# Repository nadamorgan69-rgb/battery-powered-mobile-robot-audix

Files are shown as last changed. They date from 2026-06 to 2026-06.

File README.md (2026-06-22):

# Battery Powered Mobile Robot - Audix

Audix is a battery-powered mobile robot developed for warehouse-style auditing, navigation, sensing, and low-level motion control. This repository brings together the project software, simulation work, embedded control code, electrical design files, documentation, media, and test assets in one place.

## Project Overview

Audix combines several connected subsystems:

- ROS 2 robot software for mission control, sensing, dashboard access, and service orchestration
- Gazebo and RViz simulation assets for robot visualization and behavior testing
- ESP32 embedded control and bench firmware for mecanum motion, PID tuning, IMU feedback, and hardware validation
- electrical design resources including battery sizing, wiring, PCB files, and LTspice documentation
- project documentation, archive files, images, and simulation videos

## Key Components

- `source-repositories/ros2_ws/`
  ROS 2 runtime workspace for the robot stack, micro-ROS communication, GPIO control, vision, dashboard services, and mission flow.

- `source-repositories/Audix/`
  Simulation-focused robot package including URDF, Gazebo launch files, RViz configuration, controllers, and robot meshes.

- `source-repositories/esp32-mecanum-yaw-hold/`
  Standalone ESP32 bench firmware for mecanum yaw hold, heading correction, wheel RPM validation, and control tuning.

- `source-repositories/aduix-esp32-windows-test/`
  Windows-based ESP32 testing sandbox for isolated hardware bring-up, motor checks, IMU checks, encoder validation, and stepper testing.

## Repository Layout

- `documentation/`
  Final project report and written documentation.

- `electrical/battery-sizing/`
  Battery sizing calculations and related electrical planning files.

- `electrical/wiring-schematic/`
  Wiring schematic and Fritzing-based electrical layout files.

- `electrical/pcbs-full-files/`
  PCB project source files.

- `electrical/ltspice-simulation/`
  LTspice simulation documentation.

- `archives/`
  Project archive files and packaged design assets.

- `assets/images/`
  Robot photos, rendered visuals, and PCB screenshots.

- `assets/videos/`
  Simulation videos and recorded motion results.

## Project Images

### Physical Robot

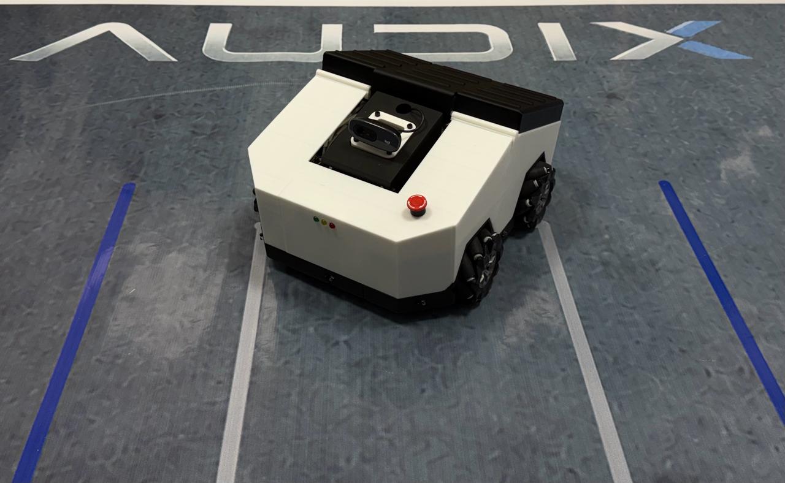
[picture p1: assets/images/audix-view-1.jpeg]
Audix view 1


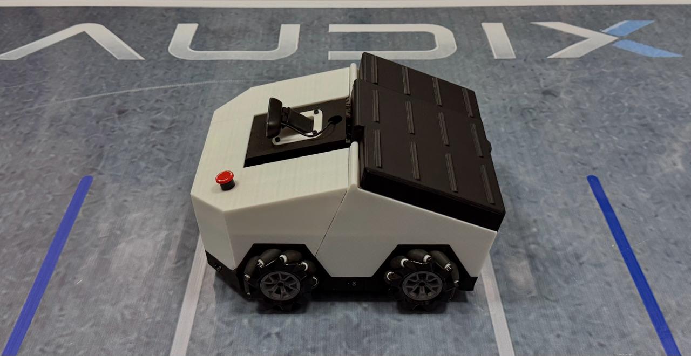
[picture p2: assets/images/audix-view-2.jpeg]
Audix view 2


### Design And PCB Visuals

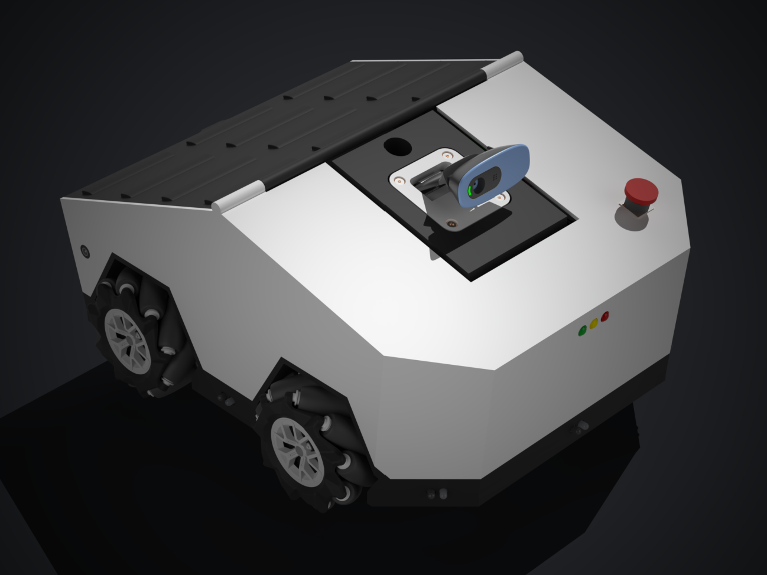
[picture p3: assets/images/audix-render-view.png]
Audix render view


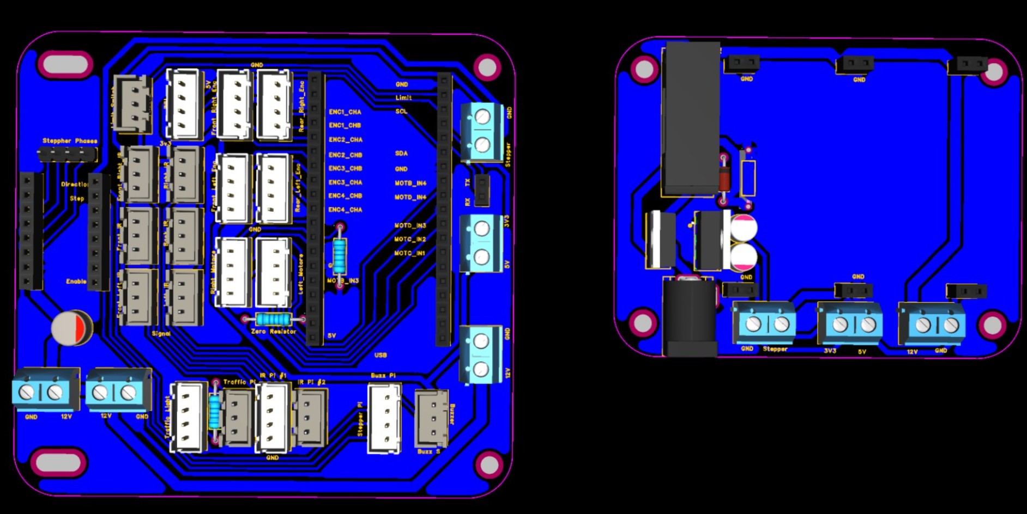
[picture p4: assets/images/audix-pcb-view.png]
Audix PCB view


## Main Project Files

- Final documentation: `documentation/audix-final-documentation.pdf`
- User manual: `documentation/AUDIX_User_Manual_landscape_no_margin/AUDIX_User_Manual_landscape_no_margin.pdf`
- Final poster: `documentation/Final Poster (1)/Final Poster (1).pdf`
- Team's card: `documentation/Audix ( Team's Card)/Audix ( Team's Card).pdf`
- Battery sizing: `electrical/battery-sizing/battery-sizing.pdf`
- Wiring schematic: `electrical/wiring-schematic/fritzing-version-1-stepper-ir.fz`
- PCB project: `electrical/pcbs-full-files/design-2.eprj`
- LTspice simulation: `electrical/ltspice-simulation/ltspice-simulation.pdf`
- Project archive: `archives/audix-mk1.rar`
- Full Mission video: `assets/videos/full-mission.mp4`

## Simulation Media

- `assets/videos/full-mission.mp4` - Full Mission
- `assets/videos/midterm-simulation-1.mp4`
- `assets/videos/midterm-simulation-2.mp4`
- `assets/videos/midterm-simulation-3.mp4`

## Notes

- Large media files such as `.rar` archives and `.mp4` videos are tracked with Git LFS.
- This repository is organized as a full project record, covering software, hardware, design, and documentation together.

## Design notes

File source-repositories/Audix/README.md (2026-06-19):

# Audix ROS2 Simulation Workspace

## Project Status (Where We Reached)
This workspace has been migrated to ROS 2 (Jazzy) with Gazebo (ros_gz) and is currently running a working simulation pipeline for the Audix robot.

Implemented so far:
- ROS 2 package setup with `ament_cmake` and install rules.
- Gazebo simulation launch with world loading and robot spawning.
- URDF integration with `robot_state_publisher`.
- `ros_gz_bridge` topic bridges for clock, odometry, joint states, IMU, lidar scan, and velocity command.
- `ros2_control` + `diff_drive_controller` integration.
- EKF localization node (`robot_localization`) enabled for fused state estimation.
- RViz launch and default visualization config.
- Initial behavior scripts for obstacle avoidance and waypoint motion.

Current known scope:
- Main drivetrain currently behaves as differential drive in simulation.
- Team roadmap below includes planned migration/tuning toward mecanum-specific behavior and a fuller warehouse-like environment.

## Quick Start
Use these commands from the repository root:

```bash
source /opt/ros/jazzy/setup.bash
colcon build --packages-select audix
source install/setup.bash
```

Launch Gazebo simulation:

```bash
ros2 launch audix robot_gazebo.launch.py
```

Launch RViz visualization-only flow:

```bash
ros2 launch audix display_rviz.launch.py
```

## What Each Launch File Does
- `src/audix_pkg/launch/robot_gazebo.launch.py`
  - Main simulation entrypoint.
  - Starts Gazebo, robot state publisher, bridges, robot spawn, and EKF.
- `src/audix_pkg/launch/gazebo.launch.py`
  - Wrapper that includes `robot_gazebo.launch.py`.
- `src/audix_pkg/launch/display_rviz.launch.py`
  - RViz-focused launch (URDF, joint state publisher/gui, robot state publisher, RViz2).
- `src/audix_pkg/launch/display.launch.py`
  - Wrapper that includes `display_rviz.launch.py`.

## Config and World Files (High-Level)
- `src/audix_pkg/config/controllers.yaml`
  - Controller manager and drive controller parameters (wheel names, geometry, limits, cmd format).
- `src/audix_pkg/config/ekf.yaml`
  - EKF fusion settings (odom + IMU) and TF publishing behavior.
- `src/audix_pkg/rviz/config.rviz`
  - Default RViz display layout and fixed frame.
- `src/audix_pkg/world/my_world.sdf`
  - Main simulation world (ground plane, lighting, example obstacle, physics/sensor systems).
- `src/audix_pkg/world/empty_world.sdf`
  - Minimal baseline world variant.

## Simulation Pipeline Overview
1. Build and source the workspace.
2. Launch Gazebo world.
3. Publish robot URDF to `robot_description`.
4. Spawn robot entity in Gazebo from `robot_description`.
5. Bridge Gazebo/ROS topics (`/clock`, `/odom`, `/imu`, `/scan`, `/joint_states`, `/cmd_vel`).
6. Run control and localization (`ros2_control`, diff drive, EKF).
7. Optionally visualize in RViz.

## Team Roadmap (Organized TODO)

### A. Robot Frames, Geometry, and Spawn Accuracy
1. Make `RobotBody` coincide with the robot CG (not a corner/reference artifact).
2. Update spawn height so robot starts above the floor by the CG-to-lowest-wheel-point offset.
3. Add dedicated IR sensor frames in SolidWorks and keep URDF frame mapping consistent.
4. Add a frame at the exact IMU location for accurate simulation alignment (IMU frame can differ from CG).
5. Simplify RViz defaults by hiding extra mechanism links that reduce readability.

### B. Mecanum Drivetrain Study and Motion Mapping
1. Study mecanum wheel kinematics and control requirements.
2. Define and validate motion mapping for: forward, backward, left, right, rotate, and combined steering.
3. Ensure controller architecture supports mecanum behavior instead of diff-drive assumptions where needed.

### C. Environment and Obstacles
1. Define dynamic obstacle strategy:
   - How many obstacles.
   - Spawning method.
   - Motion behavior and test scenarios.
2. Design shelves and inventory layout to match the expected real environment.
3. Build the full Gazebo environment to reflect expected operational conditions.

### D. Controls, Scripts, and Mechanism Automation
1. Decide what extra scripts are required and how customizable the GUI/control interface should be.
2. Integrate scissor-lift motion mapping (from MATLAB) into an automation script:
   - Camera height command in.
   - Coordinated link motion out.

### E. Midterm Planning and Validation Scope
1. Prepare a clear checklist of all midterm deliverables and acceptance criteria.
2. Decide perception scope:
   - Whether camera sensing/object detection is required in simulation.
   - Required reactions/behaviors if detection is enabled.

### F. Data, Calibration, and Visual Fidelity
1. Collect and track all key dimensions, speeds, and relevant physical parameters to improve simulation accuracy.
2. Apply robot coloring/material styling for clearer visualization and team demos.

## Editing Guidance (For Future Team Members)
- Adjust drivetrain and controller behavior in `config/controllers.yaml` and matching wheel/joint definitions in URDF.
- Update localization behavior in `config/ekf.yaml`.
- Modify world geometry and obstacles in `world/my_world.sdf`.
- Keep frame naming consistent across SolidWorks export, URDF, controllers, and RViz.
- After any change:
  1. Rebuild package.
  2. Re-source `install/setup.bash`.
  3. Relaunch and validate topics/TF.

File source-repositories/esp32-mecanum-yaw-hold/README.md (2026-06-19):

# ESP32 Mecanum Yaw Hold Bench

Standalone Audix-aligned ESP32 test firmware for mecanum yaw hold, straight-line
heading correction, wheel RPM validation, and a small HTTP dashboard.

This repo is intentionally separate from the real firmware folders:

- read-only reference sandbox: `C:\Users\TiBa\Documents\PlatformIO\Projects\audix_esp32_windows_test`
- read-only final Pi firmware: `C:\Users\TiBa\OneDrive\Spring 26\Design 2\audix_wps\microROS\firmware\esp32_low_level`
- editable yaw-hold test target: `C:\Users\TiBa\Documents\PlatformIO\Projects\esp32_mecanum_yaw_hold`

The old single-file `.ino` test sketch is not the active firmware path here.
This project mirrors the Audix Windows sandbox structure: `src/`, `include/`,
FreeRTOS tasks, shared state, IMU driver, encoder odometry, mecanum kinematics,
wheel PID, HTTP API, and a SPIFFS dashboard.

## What Changed

- Added explicit `imu cal`, `imu zero`, and `imu reset` commands.
- Added `yawhold zero`, `yawhold on`, and `yawhold off`.
- Straight `forward <cm>` and `backward <cm>` now keep heading hold active at
  the captured starting yaw after the distance target finishes.
- Still yaw hold commands chassis `wz` through the normal mecanum inverse
  kinematics path instead of directly poking wheel RPMs.
- Added a zero-output gate in the wheel PID task so tiny target and encoder
  noise near zero does not get boosted into audible motor-deadband ticks.
- Extended `/api/state` with heading and command-path diagnostics.
- Simplified the dashboard to the yaw-hold bench flow: setup, hold/release,
  forward/backward/rotate, RPM validation, wheel/yaw PID tuning, and raw log.

## Build

```powershell
cd "C:\Users\TiBa\Documents\PlatformIO\Projects\esp32_mecanum_yaw_hold"
pio run -e esp32_wifi_base_dashboard
pio run -e esp32_wifi_base_dashboard -t buildfs
```

## Flash Over USB

Replace `COM10` if your ESP32 is on another port.

```powershell
cd "C:\Users\TiBa\Documents\PlatformIO\Projects\esp32_mecanum_yaw_hold"
pio run -e esp32_wifi_base_dashboard -t upload --upload-port COM10
pio run -e esp32_wifi_base_dashboard -t uploadfs --upload-port COM10
```

If you need to find the port:

```powershell
pio device list
```

Serial monitor:

```powershell
pio device monitor -p COM10 -b 115200
```

## Open The GUI

Connect the laptop to:

```text
SSID: AudixBench-ESP32
Password: audixbench123
```

Open:

```text
http://192.168.4.1/
```

Direct API checks:

```text
http://192.168.4.1/api/ping
http://192.168.4.1/api/state
http://192.168.4.1/api/history
http://192.168.4.1/api/command?line=status
```

## Hardware Mapping

Firmware wheel order is `FL, FR, RL, RR`.

| Wheel | Motor label | Motor GPIOs | Encoder label | Encoder GPIOs |
| --- | --- | --- | --- | --- |
| Front Left | MOTD | `17, 18` | ENC2 | `34, 35` |
| Front Right | MOTB | `13, 19` | ENC3 | `33, 32` |
| Rear Left | MOTC | `4, 16` | ENC1 | `39, 36` |
| Rear Right | MOTA | `27, 14` | ENC4 | `25, 26` |

The motor driver is two-input H-bridge style:

- positive command: `IN1 = PWM`, `IN2 = LOW`
- negative command: `IN1 = LOW`, `IN2 = PWM`
- stop: both inputs `LOW`

## Fast Bench Flow

Keep the robot on blocks until wheel direction, encoder mapping, RPM feedback,
and stop behavior are correct.

```text
stop
i2cscan
imu cal
encoders zero
rpm fl 60 2.0
rpm fr 60 2.0
rpm rl 60 2.0
rpm rr 60 2.0
rpms all 60 2.0
yawhold zero
```

Twist the robot by hand and release it. Expected result:

- it returns to the captured yaw
- heading error returns inside `+/-3 deg` without repeated sign-flip hunting
- `heading.commandWz` returns to `0`
- wheel PWM returns to `0` when settled

Then test commanded motion:

```text
forward 20
backward 20
rotate 90
rotate -90
stop
```

`rotate 90` means counter-clockwise. `rotate -90` means clockwise.

## Important Commands

```text
stop
status
quiet
i2cscan
imu cal
imu zero
imu reset
encoders zero
encoders once
encoders on
yawhold on
yawhold off
yawhold zero
forward 20
backward 20
rotate 90
rotate -90
rpm fl 60 2.0
rpms all 60 2.0
pid show
pid wheel 1.20 0.80 0.05
pid yaw 2.00 0.00 0.06
```

## Documentation

- `docs/yaw_hold_test_procedure.md`: hardware validation order and pass/fail criteria.
- `docs/tuning_guide.md`: 10 to 15 minute tuning procedure and symptom map.
- `docs/rtos_porting_notes.md`: how to move only the controller logic into the local RTOS firmware.
- `docs/architecture.md`: module map for this standalone test firmware.

## RTOS Applicability

If this test works, the yaw-hold controller is applicable to the local ESP32 RTOS
firmware. Port only the controller logic: angle wrapping, hold state, deadband,
P plus gyro damping, command clamp, zero-output gate, settle criteria, and
telemetry. Do not copy WebServer, SPIFFS dashboard, Arduino `String` JSON, or
sketch-specific command handlers into the RTOS firmware.

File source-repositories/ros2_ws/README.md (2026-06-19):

# Audix ROS 2 Workspace

This workspace runs the Audix Raspberry Pi robot stack. It connects the Pi, ESP32
micro-ROS firmware, GPIO hardware, IR sensors, scissor lift, webcam, YOLO shelf
scanner, robot mission manager, and a simple browser dashboard.

The main launcher is `robot_start.sh`. It starts the full robot stack and prints
the dashboard URL, normally `http://<pi-ip>:8080`.

## What This Workspace Does

Audix is a small warehouse audit robot. The ROS workspace:

- Receives telemetry from the ESP32 drive controller through micro-ROS.
- Sends drive commands to the ESP32 as text commands on a ROS topic.
- Reads six IR proximity sensors from Raspberry Pi GPIO.
- Controls a buzzer and stepper-driven scissor lift through Raspberry Pi GPIO.
- Runs a webcam node and a YOLO shelf scanning service.
- Provides high-level robot services for manual movement, rotation, homing, stop,
  and shelf audit missions.
- Serves a simple web dashboard that calls ROS services and displays telemetry,
  IR state, camera frames, mission events, and vision scan results.

## Packages

| Package | Purpose |
| --- | --- |
| `audix_interfaces` | Custom ROS messages and services used by the robot stack. |
| `audix_robot` | Pi-side control nodes, robot manager, GPIO hardware, micro-ROS bridge, and web dashboard. |
| `warehouse_vision` | Webcam publisher and YOLO shelf audit service. |
| `firmware/audix_esp32_microros` | ESP32 micro-ROS firmware. It subscribes to drive commands and publishes telemetry JSON. |

## Main Launch Files

| File | Purpose |
| --- | --- |
| `launch/audix_main.launch.py` | Full runtime stack used by `robot_start.sh`: micro-ROS agent, base node, GPIO node, manager, webcam, vision, dashboard. |
| `launch/audix_bridge.launch.py` | Smaller bridge-only launch: micro-ROS agent, base node, GPIO node. No manager, vision, or dashboard. |

Default namespace is `/audix`, so relative names like `esp/telemetry` appear as
`/audix/esp/telemetry`.

## Nodes Started By `robot_start.sh`

| Node | Package / executable | Main job |
| --- | --- | --- |
| `/micro_ros_agent` | `micro_ros_agent micro_ros_agent` | Serial micro-ROS transport to ESP32 on `/dev/ttyAMA0` by default. |
| `/audix/micro_ros_base` | `audix_robot micro_ros_base_node` | Converts ESP32 micro-ROS telemetry JSON into ROS messages and exposes low-level drive services. |
| `/audix/gpio_hardware` | `audix_robot gpio_hardware_node` | Reads IR sensors and controls buzzer/lift GPIO. |
| `/audix/robot_manager` | `audix_robot robot_manager_node` | High-level command gate, manual safety, homing, map audit mission, lift/vision orchestration. |
| `/audix/webcam` | `warehouse_vision webcam_node` | Publishes camera frames. |
| `/audix/vision_audit` | `warehouse_vision vision_audit_node` | Runs YOLO scan service for shelf/product checking. |
| `/audix/web_dashboard` | `audix_robot web_dashboard_node` | Serves the simple browser dashboard and HTTP API. |

When the ESP32 firmware is connected through the micro-ROS agent, it creates the
micro-ROS node `/audix/esp32_controller`. That firmware node subscribes to
`/audix/esp/move_goal` and publishes `/audix/esp/telemetry_json`.

## Other Executable Nodes

These console scripts are available from `setup.py` but are not launched by
`robot_start.sh`.

| Executable | Purpose |
| --- | --- |
| `terminal_move_node` | Keyboard/terminal client for direction moves, rotate, stop, reset odom, init IMU. |
| `terminal_teleop_node` | Keyboard/terminal RPM teleop using the `/audix/twist` service. |
| `hello_node` | Small test/demo node in `warehouse_vision`. |

There is also an older source file, `audix_robot/esp_uart_bridge_node.py`, for a
direct UART JSON bridge. It is not used by `robot_start.sh`; the current stack
uses micro-ROS.

## Topics

| Topic | Type | Publisher | Subscriber | Purpose |
| --- | --- | --- | --- | --- |
| `/audix/esp/move_goal` | `std_msgs/String` | `micro_ros_base_node` | ESP32 firmware | Text commands to the ESP32: `MOVE`, `TWIST`, `STOP`, `INIT_IMU`, `RESET_ODOM`, etc. |
| `/audix/esp/telemetry_json` | `std_msgs/String` | ESP32 firmware | `micro_ros_base_node` | Raw JSON telemetry from the ESP32. |
| `/audix/esp/telemetry` | `audix_interfaces/EspTelemetry` | `micro_ros_base_node` | `robot_manager_node`, `web_dashboard_node` | Parsed robot pose, IMU, move, RPM, PWM, encoder telemetry. |
| `/audix/esp/telemetry_raw` | `std_msgs/String` | `micro_ros_base_node` | Optional debug tools | Raw JSON telemetry republished for debugging. |
| `/audix/ir/state` | `audix_interfaces/IrState` | `gpio_hardware_node` | `robot_manager_node`, `web_dashboard_node` | Six binary IR sensor states and active sensor list. |
| `/audix/mission/event` | `std_msgs/String` | `robot_manager_node` | `web_dashboard_node` | Human-readable mission and safety events. |
| `/audix/vision/scan_result` | `std_msgs/String` JSON | `robot_manager_node` | `web_dashboard_node` | Latest audit scan result as JSON. |
| `/audix/image_raw` | `sensor_msgs/Image` | `webcam_node` | `vision_audit_node`, `web_dashboard_node` | Live camera frames. |

Note: the Next.js GUI joystick currently publishes `/cmd_vel` through rosbridge
when `NEXT_PUBLIC_ROSBRIDGE_URL` is set, but this ROS workspace does not launch a
node that subscribes to `/cmd_vel`. The working control path today is through the
manager services or the dashboard HTTP API.

## Messages

### `audix_interfaces/msg/EspTelemetry`

Parsed ESP32 telemetry:

- Header and `mode`, `seq`.
- IMU fields: `imu_ok`, `yaw_deg`, `raw_yaw_deg`, `gyro_dps`,
  `gyro_filt_dps`.
- Odom/move fields: `forward_cm`, `strafe_cm`, `progress_cm`,
  `remaining_cm`, `local_forward_cm`, `local_strafe_cm`, `move_phase`,
  `move_angle_deg`, `move_distance_cm`, `heading_target_deg`,
  `heading_error_deg`, `move_done`.
- Wheel fields: `rpm[4]`, `target_rpm[4]`, `pwm[4]`,
  `raw_encoder_counts[4]`, `signed_encoder_counts[4]`.
- `raw_json` copy of the source telemetry.

### `audix_interfaces/msg/IrState`

Six binary IR sensors:

- `front_left`, `front`, `front_right`, `right`, `back`, `left`
- `active`: names of sensors currently detecting an obstacle

## Services

All services below are normally under `/audix`.

| Service | Type | Server | Purpose |
| --- | --- | --- | --- |
| `/audix/esp/ping` | `std_srvs/Trigger` | `micro_ros_base_node` | Check for fresh ESP telemetry. |
| `/audix/esp/init_imu` | `std_srvs/Trigger` | `micro_ros_base_node` | Publish `INIT_IMU` to ESP32. |
| `/audix/esp/reset_odom` | `std_srvs/Trigger` | `micro_ros_base_node` | Reset Pi world odom accumulator and publish `RESET_ODOM`. |
| `/audix/esp/reset_encoders` | `std_srvs/Trigger` | `micro_ros_base_node` | Reset Pi odom accumulator and publish `RESET_ENC`. |
| `/audix/esp/stop` | `std_srvs/Trigger` | `micro_ros_base_node` | Publish `STOP` to ESP32. |
| `/audix/move` | `audix_interfaces/Move` | `micro_ros_base_node` | Low-level move by angle, distance, and heading. |
| `/audix/twist` | `audix_interfaces/TwistCommand` | `micro_ros_base_node` | Low-level RPM command: forward, strafe, turn. |
| `/audix/esp/raw_command` | `audix_interfaces/RawCommand` | `micro_ros_base_node` | Send custom ESP32 text command. |
| `/audix/gpio/set_buzzer` | `std_srvs/SetBool` | `gpio_hardware_node` | Turn buzzer on/off. |
| `/audix/lift/move_steps` | `audix_interfaces/LiftMoveSteps` | `gpio_hardware_node` | Move lift stepper by signed direction and step count. |
| `/audix/manager/set_mode` | `audix_interfaces/SetRobotMode` | `robot_manager_node` | Set `manual`, `mission`, or `idle`. |
| `/audix/manager/direction_move` | `audix_interfaces/DirectionCommand` | `robot_manager_node` | High-level safe movement using directions `F`, `B`, `L`, `R`, `FL`, `FR`, `BL`, `BR`. |
| `/audix/manager/rotate` | `audix_interfaces/RotateCommand` | `robot_manager_node` | Rotate left/right by degrees. |
| `/audix/manager/start_audit` | `audix_interfaces/AuditMission` | `robot_manager_node` | Start map audit mission for selected shelf sides and levels. |
| `/audix/manager/go_home` | `std_srvs/Trigger` | `robot_manager_node` | Return to odom zero/home. |
| `/audix/manager/stop` | `std_srvs/Trigger` | `robot_manager_node` | Cancel mission, stop robot, turn buzzer off, return to manual mode. |
| `/audix/scan_shelf` | `audix_interfaces/ShelfScan` | `vision_audit_node` | Run YOLO shelf scan on a fresh camera frame. |

## Custom Service Fields

| Type | Request | Response |
| --- | --- | --- |
| `Move` | `angle_deg`, `distance_m`, `heading_deg`, `timeout_s`, `wait_for_done` | `ok`, `result`, `message`, `forward_cm`, `strafe_cm`, `heading_deg`, `raw_json` |
| `TwistCommand` | `forward_rpm`, `strafe_rpm`, `turn_rpm`, `timeout_s` | `ok`, `message`, `raw_json` |
| `DirectionCommand` | `direction`, `distance_cm`, `timeout_s` | `ok`, `result`, `message`, `forward_cm`, `strafe_cm`, `heading_deg` |
| `RotateCommand` | `direction`, `degrees`, `timeout_s` | `ok`, `result`, `message`, `heading_deg` |
| `SetRobotMode` | `mode` | `ok`, `message`, `active_mode` |
| `LiftMoveSteps` | `steps`, `direction`, `speed_sps` | `ok`, `message` |
| `AuditMission` | `shelves`, `level_1`, `level_2` | `accepted`, `message` |
| `ShelfScan` | `shelf_id` | `success`, `shelf_id`, `expected_product`, `expected_count`, `detected_count`, `detected_products`, `wrong_products`, `confidence`, `status`, `message`, `image_path` |
| `RawCommand` | `command`, `timeout_s`, `wait_for_done` | `ok`, `type`, `result`, `message`, `raw_json` |

## Simple Web Dashboard

The simple GUI is served by `web_dashboard_node`, not by the Next.js app. Open:

```bash
http://<pi-ip>:8080
```

The dashboard shows:

- Current mode, last event, telemetry age, odom forward/strafe, yaw, IMU state,
  move state, and sequence number.
- Manual jog controls for 8 directions.
- Rotate left/right controls.
- STOP, home, init IMU, reset odom, buzzer, and lift controls.
- IR sensor indicators.
- Mission audit side/level selection.
- Live camera JPEG refreshed from the ROS image topic.
- Manual shelf scan and latest audit scan result/image.
- Log of HTTP API responses and mission events.

### Dashboard HTTP API

The browser calls these routes on the same Pi/dashboard host:

| Route | Method | Uses ROS service/topic |
| --- | --- | --- |
| `/` or `/index.html` | GET | Serves the dashboard HTML. |
| `/api/status` | GET | Returns cached `/audix/esp/telemetry`, `/audix/ir/state`, `/audix/mission/event`, latest scan. |
| `/api/camera.jpg` | GET | Returns latest JPEG encoded from `/audix/image_raw`. |
| `/api/audit_image?path=...` | GET | Returns annotated scan image from `~/audix/audit_images`. |
| `/api/move` | POST | Calls `/audix/manager/direction_move`. Body: `direction`, `distance_cm`, optional `timeout_s`. |
| `/api/rotate` | POST | Calls `/audix/manager/rotate`. Body: `direction`, `degrees`, optional `timeout_s`. |
| `/api/mode` | POST | Calls `/audix/manager/set_mode`. Body: `mode`. |
| `/api/audit` | POST | Calls `/audix/manager/start_audit`. Body: `shelves`, `level_1`, `level_2`. |
| `/api/stop` | POST | Calls `/audix/manager/stop`. |
| `/api/home` | POST | Calls `/audix/manager/go_home`. |
| `/api/init_imu` | POST | Calls `/audix/esp/init_imu`. |
| `/api/reset_odom` | POST | Calls `/audix/esp/reset_odom`. |
| `/api/buzzer` | POST | Calls `/audix/gpio/set_buzzer`. Body: `on`. |
| `/api/lift` | POST | Calls `/audix/lift/move_steps`. Body: `steps`, optional `direction`, optional `speed_sps`. |
| `/api/scan` | POST | Calls `/audix/scan_shelf`. Body: `shelf_id`. |

This HTTP API is the easiest bridge for an advanced GUI: keep the ROS stack
running on the Pi and have the new GUI call these endpoints.

## Next.js GUI In This Repo

There is also a separate advanced-looking Next.js GUI in:

```bash
../Audix_GUI/Audix_GUI
```

It currently uses `lib/mock-data.ts` for most robot, inventory, IR, health, and
log data. The joystick component can publish to rosbridge if
`NEXT_PUBLIC_ROSBRIDGE_URL` is set, but it publishes `geometry_msgs/Twist` to
`/cmd_vel`, and the current ROS stack does not subscribe to that topic.

To migrate this GUI to live robot data, use one of these paths:

1. Easiest path: call the existing dashboard HTTP API on port `8080`.
   - Read status from `GET http://<pi-ip>:8080/api/status`.
   - Show camera from `http://<pi-ip>:8080/api/camera.jpg`.
   - Move with `POST /api/move`.
   - Rotate with `POST /api/rotate`.
   - Stop with `POST /api/stop`.
   - Start audit with `POST /api/audit`.
   - Scan shelves with `POST /api/scan`.

2. More ROS-native path: run `rosbridge_server` and connect with `roslibjs`.
   - Subscribe to `/audix/esp/telemetry`, `/audix/ir/state`,
     `/audix/mission/event`, `/audix/vision/scan_result`, and `/audix/image_raw`
     or a compressed camera topic.
   - Call `/audix/manager/direction_move`, `/audix/manager/rotate`,
     `/audix/manager/stop`, `/audix/manager/start_audit`, `/audix/scan_shelf`,
     and the other services directly.
   - If you want joystick `/cmd_vel`, add a ROS node that subscribes to
     `/cmd_vel` and converts it into `/audix/twist` service calls, or change the
     GUI to call `/audix/twist` through rosbridge services.

3. Backend path: build a small Node/Python server beside the GUI.
   - The backend talks to ROS using `rclpy`, `rclnodejs`, or rosbridge.
   - The frontend talks to that backend over REST/WebSocket.
   - This is useful if the advanced GUI needs authentication, logging, or custom
     data shaping.

## How Data Moves Through The Robot

Command path:

```text
Browser dashboard or advanced GUI
  -> dashboard HTTP API or ROS service
  -> /audix/manager/* service
  -> /audix/move or /audix/twist service
  -> /audix/esp/move_goal topic
  -> ESP32 micro-ROS firmware
  -> motors / IMU / encoders
```

Telemetry path:

```text
ESP32 firmware
  -> /audix/esp/telemetry_json
  -> micro_ros_base_node
  -> /audix/esp/telemetry
  -> robot_manager_node and web_dashboard_node
  -> /api/status or advanced GUI ROS subscription
```

GPIO/safety path:

```text
Pi GPIO IR sensors
  -> gpio_hardware_node
  -> /audix/ir/state
  -> robot_manager_node safety logic
  -> /audix/esp/stop and buzzer when needed
```

Vision path:

```text
webcam_node
  -> /audix/image_raw
  -> vision_audit_node
  -> /audix/scan_shelf service
  -> robot_manager_node publishes /audix/vision/scan_result
  -> web_dashboard_node and GUI
```

## Running The Robot Stack

On the Raspberry Pi:

```bash
cd ~/path/to/ros2_ws
source /opt/ros/jazzy/setup.bash
colcon build --symlink-install
./robot_start.sh
```

Then open the URL printed by the script:

```bash
http://<pi-ip>:8080
```

The script automatically sources:

```bash
/opt/ros/jazzy/setup.bash
install/setup.bash
```

It also checks that `audix_robot`, `audix_interfaces`, and `micro_ros_agent` are
available before launching.

## Useful `robot_start.sh` Environment Variables

Set these before running `./robot_start.sh` when needed:

| Variable | Default | Purpose |
| --- | --- | --- |
| `AUDIX_PORT` | `/dev/ttyAMA0` | ESP32 micro-ROS serial port. |
| `AUDIX_BAUD` | `115200` | ESP32 serial baud rate. |
| `AUDIX_DASHBOARD_PORT` | `8080` | Web dashboard HTTP port. |
| `AUDIX_MOCK_IR` | `false` | Use mock IR sensor state. |
| `AUDIX_MOCK_GPIO` | `false` | Use mock GPIO outputs/lift/buzzer. |
| `AUDIX_CAMERA_ENABLED` | `true` | Start or skip webcam node. |
| `AUDIX_CAMERA_INDEX` | `0` | OpenCV camera index. |
| `AUDIX_VISION_ENABLED` | `true` | Start or skip YOLO vision node. |
| `AUDIX_VISION_CONFIDENCE` | `0.5` | YOLO confidence threshold. |
| `AUDIX_VISION_TARGET_COUNT` | `2` | Expected product count per shelf scan. |
| `AUDIX_VISION_SCAN_SETTLE` | `0.5` | Delay before scan capture during audit. |
| `AUDIX_SIDE_1_LEVEL_1_SHELF_ID` | `beans_can` | Product/shelf id for audit side 1 level 1. |
| `AUDIX_SIDE_1_LEVEL_2_SHELF_ID` | `indomie` | Product/shelf id for audit side 1 level 2. |
| `AUDIX_SIDE_2_LEVEL_1_SHELF_ID` | `indomie` | Product/shelf id for audit side 2 level 1. |
| `AUDIX_SIDE_2_LEVEL_2_SHELF_ID` | `fruit_rings_cereal` | Product/shelf id for audit side 2 level 2. |
| `AUDIX_CLEAN_START` | `true` | Stop old Audix processes before launching. |

Example mock run without hardware:

```bash
AUDIX_MOCK_IR=true AUDIX_MOCK_GPIO=true AUDIX_CAMERA_ENABLED=false AUDIX_VISION_ENABLED=false ./robot_start.sh
```

Example different dashboard port:

```bash
AUDIX_DASHBOARD_PORT=8090 ./robot_start.sh
```

## Running Individual Tools

After building and sourcing:

```bash
source /opt/ros/jazzy/setup.bash
source install/setup.bash
```

Terminal direction move UI:

```bash
ros2 run audix_robot terminal_move_node
```

Terminal RPM teleop:

```bash
ros2 run audix_robot terminal_teleop_node
```

Call a service manually:

```bash
ros2 service call /audix/manager/direction_move audix_interfaces/srv/DirectionCommand "{direction: F, distance_cm: 20.0, timeout_s: 10.0}"
```

Watch telemetry:

```bash
ros2 topic echo /audix/esp/telemetry
```

Watch IR sensors:

```bash
ros2 topic echo /audix/ir/state
```

## Running The Next.js GUI

The separate Next.js GUI is not launched by `robot_start.sh`.

```bash
cd ../Audix_GUI/Audix_GUI
npm install
npm run dev
```

It runs on:

```bash
http://localhost:4000
```

To connect it to the real Pi using the current easiest path, replace mock data
calls with fetches to:

```bash
http://<pi-ip>:8080/api/status
http://<pi-ip>:8080/api/camera.jpg
http://<pi-ip>:8080/api/move
http://<pi-ip>:8080/api/rotate
http://<pi-ip>:8080/api/stop
http://<pi-ip>:8080/api/audit
http://<pi-ip>:8080/api/scan
```

If the GUI is served from a different host/port, the dashboard API may need CORS
headers added in `web_dashboard_node.py`, or the Next.js app can proxy requests
through its own API routes.

## Quick Migration Checklist For An Advanced GUI

- Replace `lib/mock-data.ts` with live data from `/api/status` or ROS topics.
- Use `/api/camera.jpg` for the live camera preview, or add a proper MJPEG/WebRTC
  stream later.
- Map control buttons to `/api/move`, `/api/rotate`, `/api/stop`, `/api/home`,
  `/api/init_imu`, `/api/reset_odom`, `/api/buzzer`, and `/api/lift`.
- Map audit controls to `/api/audit` and shelf scan controls to `/api/scan`.
- For direct ROS integration, subscribe to `/audix/esp/telemetry`,
  `/audix/ir/state`, `/audix/mission/event`, `/audix/vision/scan_result`, and
  call the `/audix/manager/*` services.
- Do not rely on `/cmd_vel` unless you add a ROS node that converts `/cmd_vel` to
  the current `/audix/twist` or `/audix/manager/direction_move` control path.

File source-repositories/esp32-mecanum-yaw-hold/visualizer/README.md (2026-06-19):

# Audix Yaw Hold Bench GUI

This folder is uploaded to ESP32 SPIFFS and served by the Wi-Fi dashboard
firmware.

The page is intentionally narrow:

- safety/setup commands: `stop`, `status`, `quiet`, `i2cscan`, `imu cal`,
  `imu zero`, `imu reset`, `yawhold zero`, and `encoders zero`
- live odometry, IMU, heading-controller, and wheel telemetry from `/api/state`
- heading tests: `yawhold zero`, `yawhold on`, `yawhold off`, `forward`, `backward`, `rotate`
- RPM validation for one wheel or all wheels
- runtime PID controls for only `wheel` and `yaw`
- copy-ready command blocks, raw log, and manual command input

It uses HTTP polling only:

```text
GET /api/ping
GET /api/state
GET /api/history
GET /api/command?line=...
```

## Upload

```powershell
cd "C:\Users\TiBa\Documents\PlatformIO\Projects\esp32_mecanum_yaw_hold"
pio run -e esp32_wifi_base_dashboard -t uploadfs --upload-port COM10
```

## Open

```text
SSID: AudixBench-ESP32
Password: audixbench123
URL: http://192.168.4.1/
```

## Local Layout Preview

The local preview only shows the layout. Live values stay offline unless the
browser can reach the ESP32 APIs.

```powershell
cd "C:\Users\TiBa\Documents\PlatformIO\Projects\esp32_mecanum_yaw_hold\visualizer"
py -m http.server 8765
```

Open:

```text
http://localhost:8765/
```

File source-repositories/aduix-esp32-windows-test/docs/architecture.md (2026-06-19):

# ESP32 Low-Level Architecture

This directory contains the ESP32 low-level firmware for the Audix warehouse
robot hardware path.

## Intended Task Split

- command receive task
- motion control task
- sensor update task
- telemetry task
- quadrature encoder ISR handling

## Ownership Boundary

This firmware owns:
- encoder reading
- IMU reading
- limit switch reading
- mecanum inverse kinematics
- four wheel-speed PID controllers
- raw odometry generation
- PWM and direction output
- command-timeout safety
- telemetry publishing

This firmware does not own:
- EKF
- `arena_roamer.py`
- IR scan conversion
- RViz or other ROS-side debugging tools

## Module Boundaries

- `pid.cpp`: per-wheel PID controller logic
- `mecanum.cpp`: chassis command to wheel target conversion
- `odometry.cpp`: wheel-speed integration into raw odometry
- `motor_driver.cpp`: PWM and direction output abstraction
- `safety.cpp`: command timeout and enable gating
- `microros_transport.cpp`: transport and executor integration points

## Runtime Contract

Pi to ESP32:
- `/cmd_vel` as `geometry_msgs/msg/Twist`
- `/robot_enable` as `std_msgs/msg/Bool`

ESP32 to Pi:
- `/odom` as `nav_msgs/msg/Odometry`
- `/imu` as `sensor_msgs/msg/Imu`
- `/limit_switch` as `std_msgs/msg/Bool`

The firmware intentionally does not publish IR topics in this implementation,
matching the current explicit firmware instruction for this repository task.

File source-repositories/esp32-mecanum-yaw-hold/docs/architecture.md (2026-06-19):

# Test Firmware Architecture

This project is a standalone yaw-hold bench built from the Audix Windows
sandbox architecture. It is not the final Pi-facing firmware.

## Task Split

- `commandRxTask`: USB serial command parsing plus Wi-Fi dashboard command API.
- `sensorUpdateTask`: encoder sampling, odometry update, IMU update, and sensor state.
- `motionControlTask`: command timeout safety, mecanum inverse kinematics, wheel PID, motor PWM.
- `telemetryTask`: optional serial stream output for IMU, encoders, and task heartbeats.
- `serviceBenchRuntime`: high-level timed motion, target moves, RPM overrides, and yaw hold.

## Main State Objects

- `CommandState`: desired chassis `vx`, `vy`, `wz`, enable flag, command timestamp.
- `WheelState`: target wheel speeds, measured wheel speeds, encoder counts, PWM outputs.
- `OdometryState`: encoder-derived `x`, `y`, `theta`, `vx`, `vy`, and `wtheta`.
- `IMUState`: accel, gyro, and integrated yaw.
- `BenchRuntimeSnapshot`: active bench mode, target move state, RPM override state, heading hold state.
- `HeadingControlState`: public telemetry for heading phase, target, error, gyro Z, command `wz`, and stable time.

## Control Flow

Straight-line move:

```text
forward/backward command
    -> scheduleTargetMove(kX)
    -> capture current IMU yaw as heading target
    -> X PID commands chassis vx from encoder odometry
    -> yaw PID commands chassis wz from IMU yaw error
    -> inverseKinematics(vx, 0, wz)
    -> wheel PID
    -> motor PWM
    -> when X target is reached, keep yawhold active at captured target
```

Still yaw hold:

```text
yawhold on
    -> capture current IMU yaw
    -> clear timed/manual/RPM modes
    -> every control tick compute wz from heading error and gyro Z
    -> publish zero wz after deadband plus settle time
```

Rotation:

```text
rotate <deg>
    -> scheduleTargetMove(kYaw)
    -> use IMU yaw delta with wrapAngleRad
    -> command chassis wz through inverse kinematics
```

## Motor Tick Prevention

The motor driver has a physical deadband lift. Tiny nonzero PID output can become
an audible tick even when the robot is effectively stopped. The wheel control
task therefore gates zero-target wheels:

```text
if abs(target_wheel_rad_s) is tiny and abs(measured_wheel_rad_s) is tiny:
    reset that wheel PID
    force PWM = 0
```

This keeps settled yaw hold quiet without changing normal wheel velocity control.

## HTTP API

The dashboard uses HTTP polling only:

- `GET /api/ping`
- `GET /api/state`
- `GET /api/history`
- `GET /api/command?line=...`

`/api/state` includes a `heading` object:

```json
{
  "holdEnabled": true,
  "settled": false,
  "phaseName": "hold_active",
  "targetYawDeg": 0.0,
  "yawErrorDeg": -4.2,
  "gyroZ": 0.01,
  "commandWz": -0.08,
  "stableMs": 0.0
}
```

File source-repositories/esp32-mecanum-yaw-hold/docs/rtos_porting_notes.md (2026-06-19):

# RTOS Porting Notes

If this yaw-hold behavior works in the standalone Wi-Fi bench, it can be moved
to the local ESP32 RTOS firmware. Port the controller, not the dashboard.

## Copy These Concepts

- `wrapAngleRad`
- heading target capture
- heading hold active/settled phase state
- deadband check on yaw error
- rate deadband check on gyro Z
- P plus gyro damping through the yaw PID
- clamp on commanded chassis `wz`
- 250 ms settle confirmation
- zero-output gate in the wheel control task
- telemetry for phase, target yaw, yaw error, gyro Z, commanded `wz`, and stable time

## Do Not Copy These Pieces

- Wi-Fi AP setup
- `WebServer`
- SPIFFS dashboard files
- Arduino `String` JSON construction
- one-off bench command parser details
- test-only RPM/manual override scheduling if the RTOS firmware already has its own command layer

## Suggested RTOS Module Shape

Create a small controller that is called from the fixed-period motion task:

```cpp
struct HeadingHoldInput {
    bool enable;
    float target_yaw_rad;
    float current_yaw_rad;
    float gyro_z_rad_s;
    float dt_s;
};

struct HeadingHoldOutput {
    bool settled;
    float yaw_error_rad;
    float command_wz_rad_s;
    float stable_ms;
};
```

The RTOS task should own:

```text
capture target yaw
compute yaw hold command
combine vx/vy/wz
inverse kinematics
wheel PID
motor output
```

The wheel PID should remain wheel-speed tracking only. Do not move heading logic
inside each wheel controller.

## Straight-Line Port

When a straight-line command starts:

```text
target_x = requested distance from encoder odometry
target_yaw = current IMU yaw
```

Every control tick:

```text
x_error = target_x - measured_encoder_x
yaw_error = wrapAngleRad(target_yaw - imu_yaw)
vx = x_pid(x_error)
wz = yaw_hold(yaw_error, gyro_z)
wheel_targets = inverseKinematics(vx, 0, wz)
```

When X reaches tolerance:

```text
vx = 0
keep yaw hold enabled at target_yaw
when heading settled, command exact wz = 0
```

## Still Hold Port

For a manual still-hold command:

```text
yawhold on:
    target_yaw = current imu yaw
    active = true
    stable_ms = 0

yawhold off:
    active = false
    command vx = vy = wz = 0
```

## Zero-Output Gate Port

Place this in the wheel control task immediately before each wheel PID update:

```cpp
if (fabs(target_w_rad_s[i]) < WHEEL_TARGET_ZERO_EPSILON_RAD_S &&
    fabs(measured_w_rad_s[i]) < WHEEL_STOP_EPSILON_RAD_S) {
    wheel_pid[i].reset();
    pwm_output[i] = 0.0f;
    continue;
}
```

This is important because a tiny nonzero PID output can become an audible motor
tick when the motor driver applies its deadband lift.

## RTOS Validation Checklist

- Existing velocity PID behavior still passes.
- Stop command still forces all motor pins low.
- IMU yaw direction matches the standalone bench.
- Straight-line command captures yaw once at command start.
- Hold command settles with `wz = 0` and wheel PWM `0`.
- Telemetry exposes enough values to distinguish sign errors from tuning errors.

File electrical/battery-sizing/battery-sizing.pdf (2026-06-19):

Battery Sizing for the Delivery Cart Robot

### 1. Design basis and system architecture

The robot uses a 12 V Li-ion main battery pack with internal BMS. This battery powers the full electrical system except the Raspberry Pi, which is powered separately through a power bank. Therefore, the Raspberry Pi and its traffic light module are excluded from the main battery sizing.

The main battery is responsible for supplying:

- four 12 V DC drive motors
- two H-bridges
- one stepper motor for the scissor-lift mechanism
- one DRV8825 stepper driver
- six IR sensors
- four motor encoders
- two level shifters
- one ESP controller
- one MPU IMU
- one buzzer
- the 5 V rails through buck converters

The robot also includes:

- an internal battery BMS
- a reverse polarity safety circuit using MOSFET and resistors
- a fuse for overcurrent protection
- an emergency stop button
- charging provision

This means the battery sizing must satisfy both the energy requirement and the current capability requirement, while also respecting the system safety architecture.

### 2. Main assumptions used in the sizing

Because exact datasheet currents are not yet available for all devices, the following assumptions are used.

Battery assumptions

Parameter | Value
Battery chemistry | Li-ion
Battery system voltage used in calculations | 12 V
Usable depth of discharge | 80%
Overall design safety factor | 1.3
Buck converter efficiency | 90%

Actuator assumptions

Parameter | Value
Number of DC drive motors | 4
Average current per DC motor | 0.3 to 0.6 A
Stepper motor current | 2.0 A
Stepper operating state during mission | Always energized, including holding

The stepper motor is treated as a continuous load. Therefore:

Istepper = 2.0 A

### 3. Load table and operating voltages

3.1 12 V loads

Component | Quantity | Operating Voltage | Assumed Current | Notes
DC drive motor | 4 | 12 V | 0.3 to 0.6 A each | average running current
Stepper motor | 1 | 12 V through DRV8825 | 2.0 A total | continuously energized for holding and lifting
H-bridge boards | 2 | 12 V motor side | included with motor load | board losses neglected in first sizing
DRV8825 driver (VMOT side) | 1 | 12 V motor supply | included with stepper load | motor power path
Reverse polarity circuit | 1 | 12 V line | negligible | safety element
Fuse | 1 | 12 V line | negligible | protection element
E-stop button | 1 | actuator line | negligible | control/safety element

3.2 5 V loads supplied through buck converter(s)

Component | Quantity | Operating Voltage | Assumed Current Each | Total Current
IR sensors | 6 | 5 V | 0.020 A | 0.120 A
Motor encoders | 4 | 5 V | 0.020 A | 0.080 A
Level shifters | 2 | 5 V | 0.005 A | 0.010 A
ESP board | 1 | 5 V | 0.100 A | 0.100 A
MPU IMU | 1 | 5 V | 0.005 A | 0.005 A
Buzzer | 1 | 5 V | 0.010 A average | 0.010 A
DRV8825 VDD input | 1 | 5 V | 0.010 A | 0.010 A
Driver/control overhead | 1 lumped | 5 V | 0.040 A | 0.040 A

So the total 5 V load current is:

I5V,total = 0.120 + 0.080 + 0.010 + 0.100 + 0.005 + 0.010 + 0.010 + 0.040

I5V,total = 0.375 A

### 4. Buck converter check

Your buck converter provides:

- 5 V
- 3 A output

The required 5 V load current is:

0.375 A

So one 5 V, 3 A buck converter is already sufficient, because:

0.375
3

× 100 = 12.5%

This means even a single buck would be loaded to only 12.5% of its rated current. Since you already have two buck converters, this gives very good margin and flexibility.

A practical distribution consistent with your actual wiring is:

- Buck 1: ESP + MPU + IR sensors + encoders + level shifters + buzzer + general control overhead
- Buck 2: DRV8825 VDD input only

The stepper motor itself is not powered through the 5 V buck. It remains on the 12 V actuator rail through the DRV8825 motor supply path.

### 5. Converting the 5 V electronics load into equivalent battery current

First, the total power required by the 5 V electronics is:

P5V = V × I
P5V = 5 × 0.375 = 1.875 W

Now convert this to equivalent current drawn from the 12 V battery, using 90% buck efficiency:

Ibattery,aux =

P5V

Vbattery × η

Ibattery,aux =

1.875
12 × 0.9
Ibattery,aux = 0.174 A

So the always-on electronics contribute approximately:

Ibattery,aux ≈ 0.174 A

For clarity, the two-buck split can also be checked separately.

Buck 1 load

Buck 1 supplies:

- IR sensors = 0.120 A
- encoders = 0.080 A
- level shifters = 0.010 A
- ESP = 0.100 A
- MPU = 0.005 A
- buzzer = 0.010 A
- general control overhead = 0.040 A

So:

IBuck1 = 0.120 + 0.080 + 0.010 + 0.100 + 0.005 + 0.010 + 0.040 IBuck1 = 0.365 A

Its power is:

PBuck1 = 5 × 0.365 = 1.825 W

Equivalent battery current:

Ibattery,Buck1 =

1.825
12 × 0.9

= 0.169 A

Buck 2 load

Buck 2 supplies only the DRV8825 VDD input:

IBuck2 = 0.010 A

Its power is:

PBuck2 = 5 × 0.010 = 0.050 W

Equivalent battery current:

Ibattery,Buck2 =

0.050
12 × 0.9

= 0.0046 A

Therefore:

Ibattery,aux = Ibattery,Buck1 + Ibattery,Buck2

Ibattery,aux = 0.169 + 0.0046

Ibattery,aux ≈ 0.174 A

### 6. Mission profile model

Since the robot is expected to move continuously while sensing obstacles, the sizing can be simplified into two operating conditions.

Base condition

This is the dominant condition during the mission. In this state:

- four DC motors are running
- IR sensors are active
- encoders are active
- ESP is active
- MPU is active
- supporting electronics are active
- DRV8825 VDD logic input is powered from Buck 2
- the stepper motor is energized and holding position

Lift condition

This occurs when the scissor mechanism is commanded to raise. In this state:

- all base-condition loads are still active
- the stepper motor remains energized and performs motion

Because the stepper is assumed to remain energized all the time, its current is treated as a continuous contribution throughout the mission rather than duty-cycled.

Thus, the stepper’s average contribution becomes:

Istepper,avg = 2.0 A

### 7. Average battery current calculation

### 7.1 Drive motor contribution

Each motor is assumed to draw:

0.3 to 0.6 A

With four motors:

Idrive = 4 × (0.3 to 0.6)
Idrive = 1.2 to 2.4 A

### 7.2 Total average battery current

Now add the battery-side auxiliary load and the stepper average contribution:

Iavg,total = Idrive + Ibattery,aux + Istepper,avg
Iavg,total = (1.2 to 2.4) + 0.174 + 2.0

Iavg,total = 3.374 to 4.574 A

So the total average current required from the main battery is:

Iavg,total = 3.37 to 4.57 A

These updated current bounds are the basis for the rest of the sizing.

### 8. Battery capacity equation

Battery capacity is determined from:

Crequired =

Iavg,total × t × SF
DoD

Where:

- Iavg,totalis the average battery current
- tis runtime in hours

- SF = 1.3
- DoD = 0.8

So:

Crequired = Iavg,total × t ×

1.3
0.8
Crequired = Iavg,total × t × 1.625

### 9. Capacity calculations for the requested runtime range

### 9.1 For 25 minutes runtime

t =

25
60 = 0.4167 h

Lower-current case

C25,min = 3.374 × 0.4167 × 1.625 C25,min = 2.28 Ah

Higher-current case

C25,max = 4.574 × 0.4167 × 1.625 C25,max = 3.10 Ah

So for a 25-minute mission:

C25 = 2.28 to 3.10 Ah

### 9.2 For 30 minutes runtime

t = 0.5 h

Lower-current case

C30,min = 3.374 × 0.5 × 1.625 C30,min = 2.74 Ah

Higher-current case

C30,max = 4.574 × 0.5 × 1.625 C30,max = 3.72 Ah

So for a 30-minute mission:

C30 = 2.74 to 3.72 Ah

### 9.3 For 45 minutes runtime

t = 0.75 h

Lower-current case

C45,min = 3.374 × 0.75 × 1.625 C45,min = 4.11 Ah

Higher-current case

C45,max = 4.574 × 0.75 × 1.625 C45,max = 5.57 Ah

So for a 45-minute mission:

C45 = 4.11 to 5.57 Ah

### 9.4 For 60 minutes runtime

t = 1.0 h

Lower-current case

C60,min = 3.374 × 1.0 × 1.625 C60,min = 5.48 Ah

Higher-current case

C60,max = 4.574 × 1.0 × 1.625 C60,max = 7.43 Ah

So for a 60-minute mission:

C60 = 5.48 to 7.43 Ah

All of these capacity values come directly from the updated current range and runtime equation.

### 10. Energy values in watt-hours

For completeness, the corresponding nominal battery energy can be estimated as:

E = V × C

Using 12 V:

### 25 minutes

E25 = 12 × (2.28 to 3.10)
E25 = 27.4 to 37.2 Wh

### 45 minutes

E45 = 12 × (4.11 to 5.57)
E45 = 49.3 to 66.9 Wh

### 60 minutes

E60 = 12 × (5.48 to 7.43)
E60 = 65.8 to 89.2 Wh

These energy values reflect the regenerated battery-capacity range.

### 11. Interpretation of the results

The calculated battery capacity values are now higher than the very low-stepper case because:

- the Raspberry Pi is still powered from a separate power bank
- the low-power electronics still consume very little current
- the four drive motors still add 1.2 to 2.4 A
- the stepper motor is now treated as a continuous 2.0 A load
- therefore, the final battery size depends mainly on the drive motors plus the continuously energized stepper

However, in real mobile robots, especially those using four mecanum wheels, current can rise noticeably due to:

- starting current
- turning losses
- wheel slip
- floor friction
- payload variation
- obstacle avoidance maneuvers
- battery aging
- voltage sag under load

Therefore, although the mathematical requirement for a 60-minute mission is approximately 5.48 to 7.43 Ah, it is not good engineering practice to select a battery exactly equal to this value.

### 12. Final battery selection

Minimum technically acceptable choice

For a one-hour mission based on the present assumptions, the battery should be at least:

12 V Li-ion, 8 Ah

This covers the upper calculated result of 7.43 Ah with a small additional margin.

Practical recommended choice

For a safer and more robust design, the better selection is:

12 V Li-ion, 8 to 10 Ah

Recommended final choice for the report

If you want one clean recommended number to defend in the document, I suggest:

12 V | L | i-ion b | attery, 1 | 0 A | h

This is a very reasonable selection because it gives:

- margin beyond the calculated one-hour requirement
- better tolerance to motor current uncertainty
- better tolerance to mecanum drive losses
- more stable voltage under transients
- room for future additions

### 13. Peak current and BMS selection

Battery sizing is not only about Ah. The battery must also support short-duration current peaks.

Since exact motor stall current is not available, a conservative engineering estimate is to assume each motor may momentarily draw around 3 times its average current during startup or aggressive movement.

Thus, the motor peak range becomes:

Imotor,peak = 4 × (0.9 to 1.8)

Imotor,peak = 3.6 to 7.2 A

Now add:

- stepper motor continuous current = 2.0 A
- auxiliary battery-side load = 0.174 A

So the approximate system peak becomes:

Ipeak,total = 3.6 to 7.2 + 2.0 + 0.174

Ipeak,total = 5.77 to 9.37 A

Because this is still based on assumed motor behavior, the battery/BMS should be selected with clear margin.

Recommended BMS rating

BMS c | ontinuous c | urrent: a | t l | east 1 | 5 A

and preferably:

BMS c | ontinuous c | urrent: 2 | 0 A

The regenerated peak-current range supports this recommendation.

### 14. Fuse selection

The fuse must be high enough to survive normal current peaks, but low enough to protect wiring and electronics under fault conditions.

Since the estimated peak current can approach roughly 9 to 10 A, a reasonable preliminary fuse
selection is:
15 A | f | use

This is a good practical choice because it is:

- above the expected average operating current
- above likely transient current peaks
- still low enough to provide meaningful fault protection

If later testing shows much higher startup current, then the fuse may be adjusted accordingly.

### 16. Short final design statement for the report

The robot is powered by a 12 V Li-ion main battery pack with internal BMS, while the Raspberry Pi is supplied separately by a power bank and is therefore excluded from the main battery sizing. The main battery powers the four 12 V DC drive motors, the stepper-based scissor-lift mechanism through a DRV8825 driver, the ESP controller, the IR sensors, encoders, level shifters, IMU, buzzer, and the 5 V auxiliary rail through buck conversion. The DRV8825 motor supply remains on the 12 V actuator rail, while a separate 5 V buck converter is connected only to the DRV8825 VDD input. Based on an assumed average current of 0.3 to 0.6 A per drive motor, a continuously energized stepper current of 2.0 A, and a total 5 V auxiliary current of 0.375 A, the equivalent average main-battery current is estimated to be 3.37 to 4.57 A. After applying a design safety factor of 1.3 and limiting usable depth of discharge to 80%, the required battery capacity is approximately 2.28 to 3.10 Ah for 25 minutes, 4.11 to 5.57 Ah for 45 minutes, and 5.48 to 7.43 Ah for 60 minutes of operation. To ensure reliable real-world performance and to account for uncertainty in actual motor current, a practical battery selection of 12 V, 10 Ah Li-ion is recommended. A BMS rating of at least 15 A, preferably 20 A, together with a 15 A fuse, is considered appropriate for the current design stage.

### 17. Final selected values

Item | Selected / Recommended Value
Main battery chemistry | Li-ion
Main battery voltage | 12 V
Minimum acceptable battery size | 8 Ah
Recommended battery size | 10 Ah
Buck converter rating | 5 V, 3 A
Required total 5 V load current | 0.375 A
Buck 1 output current | 0.365 A
Buck 2 output current | 0.010 A
Recommended BMS current rating | 15 to 20 A
Recommended fuse | 15 A
Stepper motor supply path | 12 V through DRV8825 VMOT
Stepper driver VDD supply path | 5 V through Buck 2
Raspberry Pi supply | separate power bank

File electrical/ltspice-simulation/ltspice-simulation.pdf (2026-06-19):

Robot PCB — LTSpice Simulation Documentation | | | Design 2 · V1.0 · March 2026

# LTSPICE SIMULATION

## Pre-PCB Circuit Verification Report

Design 2 · Version 1.0 · March 2026 · LTSpice XVII · Battery Indicator & Reverse Polarity Circuits

## 1. Purpose & Scope

Before committing the design to PCB, two critical analogue sub-circuits were simulated in LTSpice to verify their behaviour under real operating conditions. These circuits contain no microcontroller — they rely entirely on passive components and analogue ICs, making simulation especially important for validating threshold values and logic transitions.

Circuit | | What Was Verified
Reverse Polarity Protection | P-channel MOSFET blocks current when supply polarity is reversed; passes cleanly under correct polarity
Battery Level Indicator | Three-zone LED logic (GREEN / YELLOW / RED) transitions at the correct voltage thresholds as the battery discharges

## 2. LTSpice Simulation Schematic

The schematic below shows the full simulation setup. It is divided into four functional sections from left to right: voltage sensing divider and reference generation, two LTC1441 comparator stages (green and red), the yellow LED wired-OR/NAND logic, and the P-channel MOSFET reverse polarity protection sub-circuit.

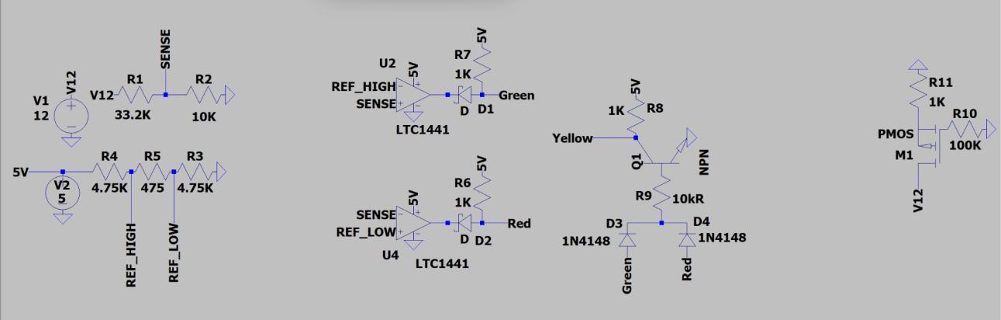
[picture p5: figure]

Figure 1 — Full LTSpice simulation schematic. Left: SENSE and REF dividers. Centre: LTC1441 comparators for green and red. Right-centre: 1N4148 diode OR gate + NPN transistor yellow logic. Far right: PMOS reverse polarity protection.

## 3. Simulation vs. PCB Component Equivalents

LTSpice does not include every component used on the physical PCB. Where a direct model was unavailable, functionally equivalent components were substituted. The table below documents every substitution and confirms that the simulation results are valid for the actual PCB components.

LTSpice Component | Real PCB
Component | Function | Reason for Substitution
LTC1441 (U2, U4) | LM393AP (U11) | Dual comparator | LTC1441 not in LTSpice library; functionally equivalent open-collector dual comparator
PMOS M1 (generic) | IRF4905P | Reverse polarity protection | Generic PMOS used to validate switching behaviour; IRF4905P is the PCB component
R1 = 33.2kΩ | R1 = 33kΩ (E24) | SENSE divider top | 33.2k is E96 precision value; 33k E24 used on PCB — negligible difference
R4/R3 = 4.75kΩ | 4.7kΩ (E24) | REF divider arms | 4.75k E96 vs 4.7k E24 — shifts thresholds by <1%
R5 = 475Ω | 470Ω (E24) | REF divider mid | Same E96 vs E24 approximation — negligible
R7/R6 = 1kΩ | 330Ω | LED pull-up | Simulation uses 1k to keep LED currents clean; PCB uses 330Ω for brighter drive
1N4148 (D1–D4) | 1N4148 (D2, D3) | Open-collector & diode OR gate | Same component — LTSpice models D-type

output of LTC1441 + wired-OR diodes

Q1 NPN | 2N3904TAR (Q2) | Yellow NAND logic | Generic NPN used in simulation; 2N3904TAR is the PCB component
V1 = 12V (swept/ramped) | 12V battery / input rail | Battery voltage source | Simulated as ideal source; real battery sags under load

Note: All substitutions are functionally equivalent for the purposes of these simulations. Threshold voltages calculated from E24 resistor values on the PCB are within 1% of the E96 values used in simulation.

## 4. Simulation 1 — Reverse Polarity Protection (DC Sweep)

### 4.1 Objective

To verify that the P-channel MOSFET (modelled as a generic PMOS in LTSpice, IRF4905P on the PCB) correctly blocks current when the input supply is connected with reversed polarity, and conducts normally under correct polarity.

### 4.2 Setup

- Simulation type: DC Sweep
- Swept variable: V(v12) — input supply voltage
- Sweep range: −12.6V to +11.4V in 0.01V steps
- Observed node: V(n002) — the output of the PMOS source (equivalent to 12V_MAIN on the PCB)
- Gate pulled to GND via R10 (100kΩ) — keeps PMOS on under correct polarity
- R11 (1kΩ) represents the load on the output node

### 4.3 Result

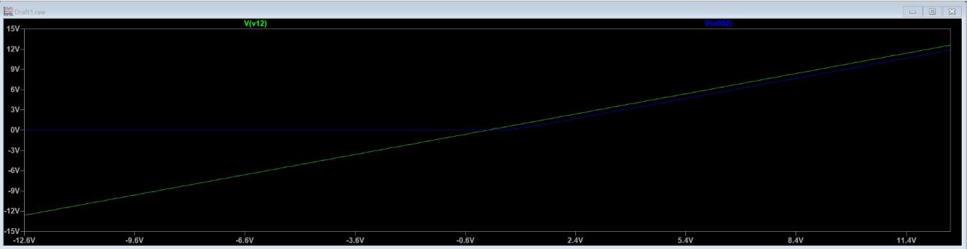
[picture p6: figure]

Figure 2 — DC Sweep result. Green trace: V(v12) input voltage. Blue trace: V(n002) output voltage. The output holds at 0V for all negative inputs and follows the input linearly for positive voltages.

The result clearly shows two regions:
- Negative input (left half of graph): V(n002) remains flat at approximately 0V — the PMOS is off, reverse current is blocked. The small residual (~0V) confirms no reverse conduction path through the MOSFET body diode in this configuration.
- Positive input (right half of graph): V(n002) follows V(v12) with a very small drop (Vds_on of the PMOS) — the MOSFET is fully on, passing current with minimal loss.
Note: The IRF4905P has a typical Rds(on) of 20mΩ at Vgs = −10V, meaning the voltage drop at nominal current is negligible. This is the key advantage over a diode-based reverse polarity solution, which would waste 0.3–0.7V as heat.

### 4.4 Conclusion

The PMOS reverse polarity protection circuit performs exactly as designed. Reversed polarity is blocked with no damage to downstream components. Correct polarity passes with effectively zero loss. The design is confirmed suitable for the PCB.

## 5. Simulation 2 — Battery Level Indicator (Transient)

### 5.1 Objective

To verify that the three-zone battery indicator logic (GREEN / YELLOW / RED) transitions between states at the correct voltage thresholds, in the correct order, as the battery voltage decays from full charge to a low state.

### 5.2 Setup

- Simulation type: Transient
- Duration: 3 seconds
- V(v12): Ramped from 12V at t=0 down to approximately 9V at t=3s — simulating a discharging battery
- Observed nodes: V(v12) (blue), V(yellow) (green trace), V(green) (green trace), V(red) (red trace)
- Reference voltages: REF_HIGH ≈ 3.6V, REF_LOW ≈ 3.1V (generated by the 4.75kΩ / 475Ω / 4.75kΩ divider from 5V)
- SENSE voltage tracks V(v12) proportionally via the 33.2kΩ / 10kΩ divider

### 5.3 Result

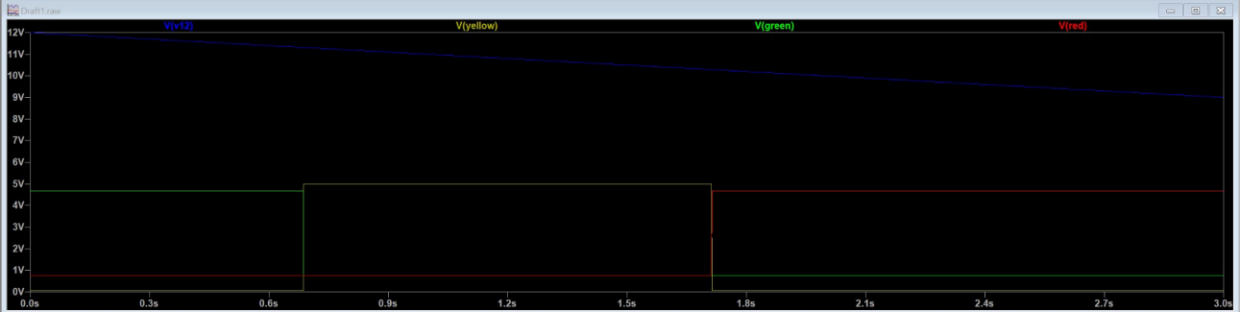
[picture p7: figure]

Figure 3 — Transient result. Blue: V(v12) battery voltage decaying 12V→9V. Green (upper): V(green) LED signal — HIGH initially then switches OFF. Green (lower, square pulse): V(yellow) LED signal — pulses ON in the middle zone. Red: V(red) LED signal — OFF initially, switches ON in the final zone.

Event | Time (approx.) | V(v12) at transition | LED Change
Simulation start | t = 0s | ~12V | GREEN ON, yellow/red OFF
GREEN → YELLOW | t ≈ 0.7s | ~11.2V | GREEN OFF, YELLOW ON
YELLOW → RED | t ≈ 1.75s | ~9.7V | YELLOW OFF, RED ON
Simulation end | t = 3s | ~9V | RED ON, others OFF

The transient plot shows three clearly defined and cleanly separated states:
- 0s to ~0.7s — GREEN ON: Battery voltage is high (SENSE > REF_HIGH). U2 (green comparator) output is LOW, pulling TRAF_G LOW and illuminating the green LED. Both diodes D3/D4 hold Q1 off, keeping yellow dark.
- ~0.7s to ~1.75s — YELLOW ON: Battery has discharged to the middle zone (REF_LOW < SENSE < REF_HIGH). Both comparator outputs float. Neither diode conducts. Q1 base has no drive, Q1 is off, and the 1kΩ pull-up drives V(yellow) HIGH. Green and red are both dark.

- ~1.75s onwards — RED ON: Battery is low (SENSE < REF_LOW). U4 (red comparator) output pulls LOW. D4 conducts, driving Q1 on, pulling yellow LOW. TRAF_R goes HIGH via the 1kΩ pull-up, illuminating red.
Note: The transitions are clean with no glitch or overlap between states. This confirms the diode wired-OR gate and NPN transistor logic correctly implements the required NAND behaviour for yellow — it only illuminates when both comparator outputs are simultaneously inactive.

### 5.4 Conclusion

The battery indicator circuit operates exactly as designed across the full discharge range. All three LED zones activate and deactivate at the correct thresholds with no false triggering. The simulation validates the component values, the comparator polarity assignments (including the corrected U11.2 pin orientation confirmed during design review), and the diode + transistor yellow logic before committing to PCB manufacture.

## 6. Overall Simulation Summary

Simulation | Type | What Was Tested | Result
Reverse Polarity | DC Sweep (−12.6V to +11.4V) | PMOS blocking behaviour under reversed input polarity | Output (n002) held at 0V for all negative inputs; follows input for positive — PASS
Battery Indicator | Transient (0–3s) | Three-zone LED sequencing as 12V rail decays to ~9V over 3 seconds | GREEN → YELLOW → RED transitions at correct thresholds in correct order — PASS

Both simulations confirm that the analogue sub-circuits are correctly designed and behave as intended before any PCB is manufactured. The component substitutions used in LTSpice are functionally equivalent to the PCB components, and the small resistor value differences between E96 (simulation) and E24 (PCB) series have negligible impact on circuit operation.

These simulations, together with the schematic review, provide high confidence that the PCB will function correctly on first build without requiring analogue rework.

Robot PCB Design · LTSpice Simulation Report · Design 2 · V1.0 · March 2026

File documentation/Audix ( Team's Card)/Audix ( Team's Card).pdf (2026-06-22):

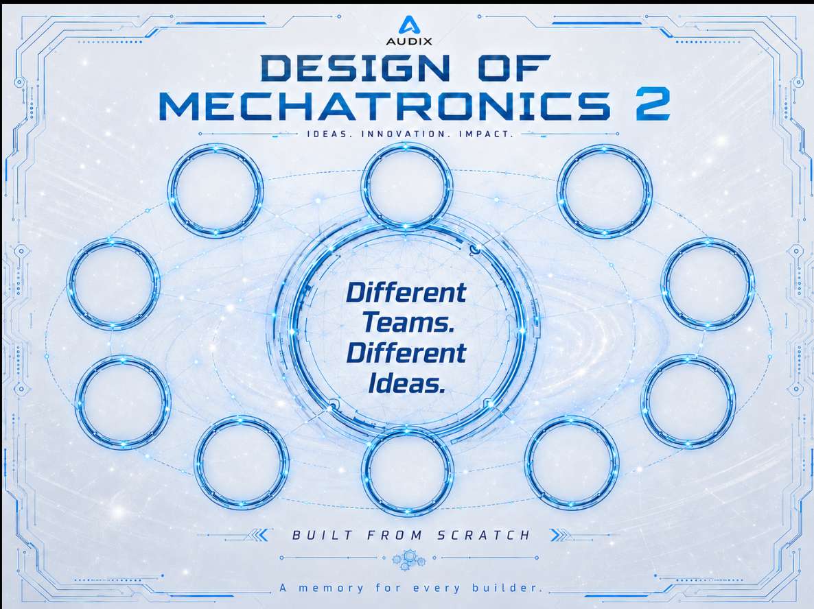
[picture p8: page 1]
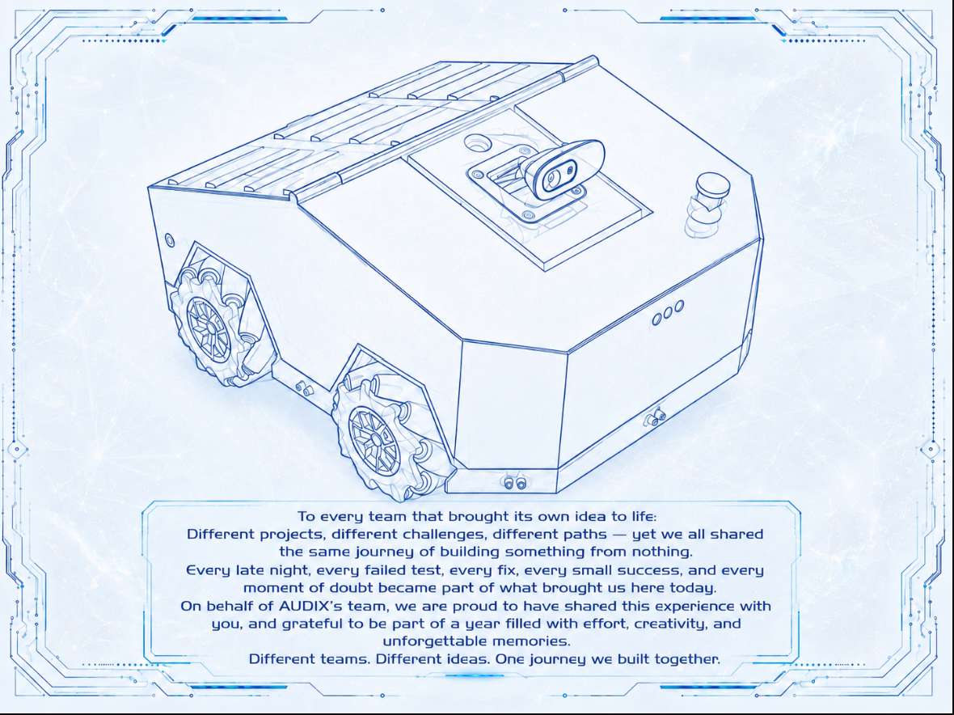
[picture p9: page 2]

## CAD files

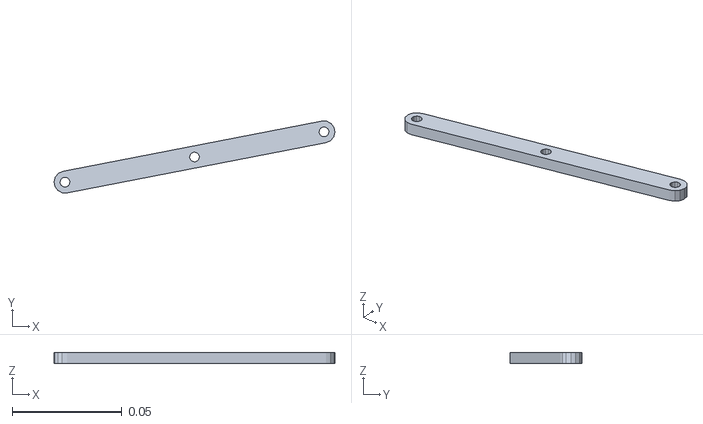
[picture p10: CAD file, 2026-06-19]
source-repositories/Audix/src/audix_pkg/meshes/left_link5.STL
0.128 x 0.0327 x 0.005

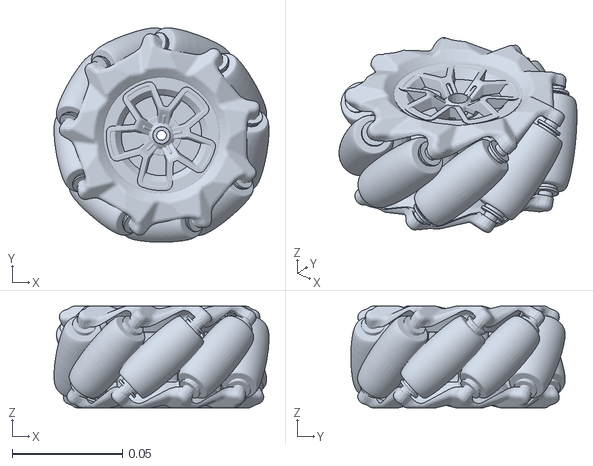
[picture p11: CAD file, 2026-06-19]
source-repositories/Audix/src/audix_pkg/meshes/back_left_wheel_link.STL
0.0973 x 0.097 x 0.046

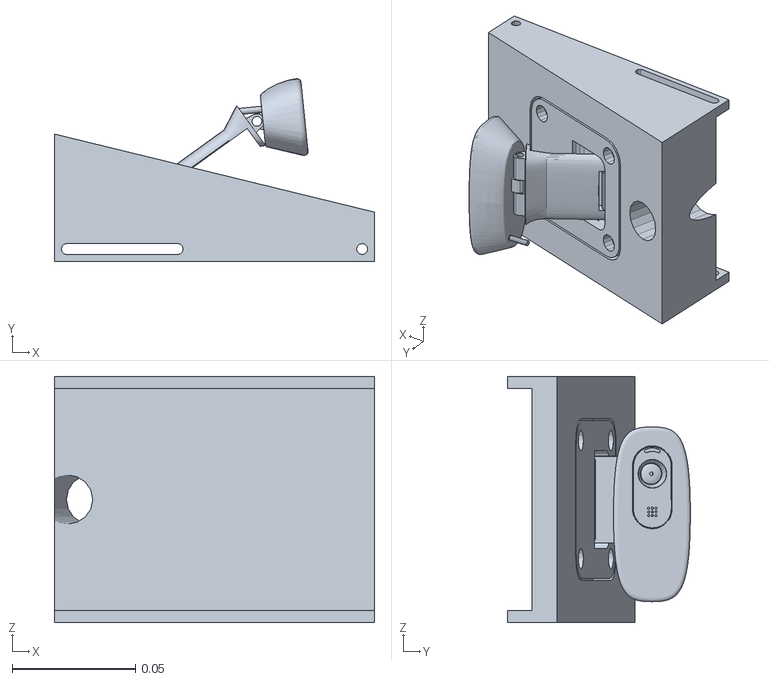
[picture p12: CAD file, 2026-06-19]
source-repositories/Audix/src/audix_pkg/meshes/camera_link.STL
0.13 x 0.0742 x 0.1

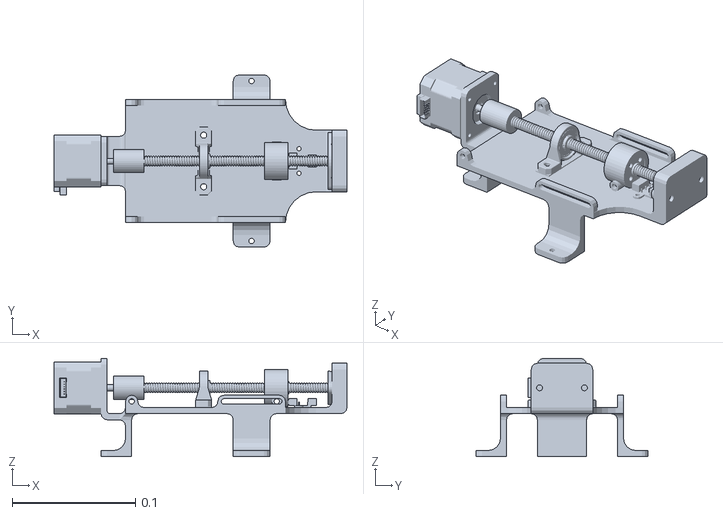
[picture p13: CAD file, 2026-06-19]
source-repositories/Audix/src/audix_pkg/meshes/scissors_lift_base.STL
0.238 x 0.14 x 0.08

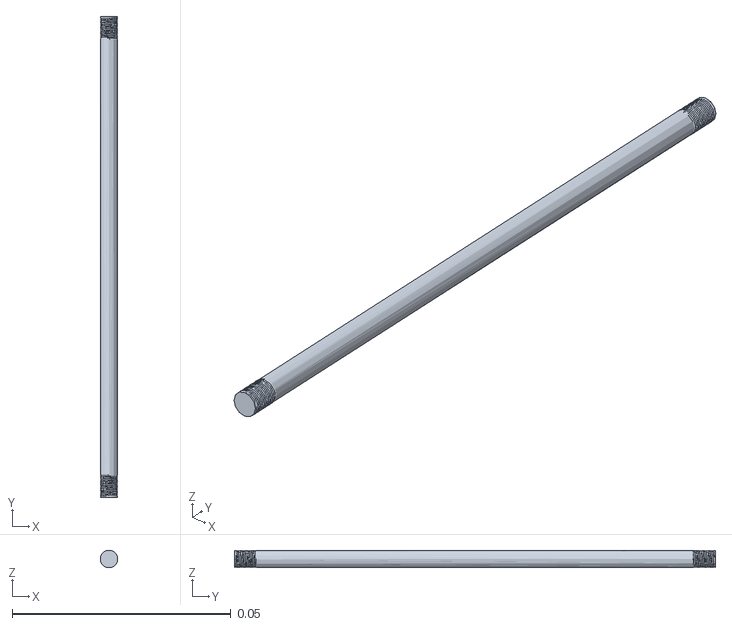
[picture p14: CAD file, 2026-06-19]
source-repositories/Audix/src/audix_pkg/meshes/top_stud_link.STL
0.004 x 0.11 x 0.004

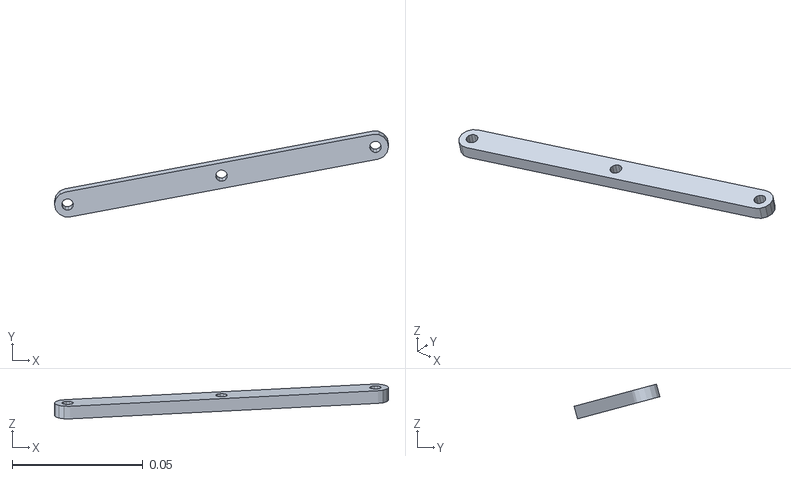
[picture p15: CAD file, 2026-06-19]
source-repositories/Audix/src/audix_pkg/meshes/right_link5.STL
0.128 x 0.0329 x 0.0133

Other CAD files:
source-repositories/Audix/src/audix_pkg/meshes/front_left_wheel_link.STL
source-repositories/Audix/src/audix_pkg/meshes/left_link3.STL
source-repositories/Audix/src/audix_pkg/meshes/front_right_wheel_link.STL
source-repositories/Audix/src/audix_pkg/meshes/bottom_stud_link.STL
source-repositories/Audix/src/audix_pkg/meshes/left_link6.STL
source-repositories/Audix/src/audix_pkg/meshes/left_link4.STL
source-repositories/Audix/src/audix_pkg/meshes/right_link2.STL
source-repositories/Audix/src/audix_pkg/meshes/left_link2.STL
source-repositories/Audix/src/audix_pkg/meshes/right_link3.STL
source-repositories/Audix/src/audix_pkg/meshes/right_link4.STL
source-repositories/Audix/src/audix_pkg/meshes/right_link6.STL
source-repositories/Audix/src/audix_pkg/meshes/back_right_wheel_link.STL
source-repositories/Audix/src/audix_pkg/meshes/base_link.STL
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

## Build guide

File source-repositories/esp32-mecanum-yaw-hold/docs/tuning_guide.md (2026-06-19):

# Yaw Hold Tuning Guide

This is a 10 to 15 minute tuning flow for the current firmware. Tune on blocks
first, then repeat on the floor at low distance.

## Starting Values

Start from these commands:

```text
pid wheel 1.20 0.80 0.05
pid yaw 2.00 0.00 0.06
```

The controller uses:

- `pid wheel`: wheel velocity tracking
- `pid yaw`: straight-line heading correction, still yaw hold, and rotation
- `HEADING_HOLD_DEADBAND_RAD`: default about 3 degrees
- `HEADING_HOLD_RATE_DEADBAND_RAD_S`: default about 2 deg/s
- `TARGET_MOVE_YAW_HOLD_LIMIT_RAD_S`: caps hold correction speed
- `HEADING_HOLD_MIN_WZ_RAD_S`: minimum return command outside the 3 degree band
- zero-output gate: forces PWM to zero when target wheel speed and measured speed are tiny

## Step 1: Confirm Wheel PID Still Works

```text
stop
encoders zero
rpm fl 60 2.0
rpm fr 60 2.0
rpm rl 60 2.0
rpm rr 60 2.0
rpms all 60 2.0
```

Do not tune yaw until RPM follows target without runaway or wrong-wheel motion.

## Step 2: Calibrate IMU Correctly

Keep the robot still:

```text
stop
imu cal
imu zero
```

Do not run `imu cal` while a wheel is moving. It will bake motion into the gyro
bias and make yaw hold act random.

## Step 3: Still Yaw Hold

```text
yawhold zero
```

Twist the robot 5 to 10 degrees and release. Watch:

- `heading.yawErrorDeg`
- `heading.commandWz`
- wheel PWM values
- audible ticks after `heading.settled = yes`

Adjustment rules:

| Symptom | Change |
| --- | --- |
| Returns too slowly and no overshoot | Increase yaw `Kp` by `0.10` to `0.20`. |
| Corrects fast but overshoots once | Increase yaw `Kd` by `0.01` to `0.02`. |
| Repeated hunting across zero | Lower yaw `Kp` by `0.10`, or raise yaw `Kd` slightly. |
| Motors tick after settled | Confirm wheel PWM is zero; if not, widen heading/rate deadband in `config.hpp`. |
| Commanded `wz` is pinned at the clamp | Reduce yaw `Kp` or raise the clamp only after sign/mapping is confirmed. |
| Twisting away makes it drive farther away | Stop and validate yaw correction sign and mecanum wheel order. |
| Yaw slowly drifts while still | Run `imu cal` while fully still, then `imu zero`. |

Keep yaw `Ki = 0` for these tests. Add integral only after the robot returns
smoothly with P and D.

## Step 4: Straight-Line Heading Hold

```text
stop
imu cal
imu zero
encoders zero
forward 20
```

Expected:

- X position reaches about `20 cm`
- yaw error stays small
- hold remains active after the distance target finishes
- PWM returns to zero after the hold settles

Adjustment rules:

| Symptom | Change |
| --- | --- |
| Drives straight but yaw correction is weak | Increase yaw `Kp` by `0.10`. |
| Wobbles left/right while moving | Increase yaw `Kd` by `0.01`, or lower yaw `Kp`. |
| Distance is wrong but yaw is good | Tune/check X odometry, CPR, wheel radius, and wheel direction before yaw. |
| Raw PWM works but straight-line command fails | Check RPM feedback and wheel PID first. |

## Step 5: Rotation

```text
rotate 90
rotate -90
```

Expected:

- positive angle is counter-clockwise
- negative angle is clockwise
- final heading stops without chatter

Adjustment rules:

| Symptom | Change |
| --- | --- |
| Rotation is too slow | Increase yaw `Kp` or `BENCH_TARGET_YAW_SPEED_RAD_S`. |
| Rotation overshoots | Increase yaw `Kd` or reduce `BENCH_TARGET_YAW_SPEED_RAD_S`. |
| Rotation reaches target but ticks after stop | Check zero-output gate telemetry: wheel target and PWM should become zero. |

## Good Enough Criteria

For the bench test to count as successful:

- a 5 to 10 degree manual twist returns to target without visible repeated hunting
- `heading.yawErrorDeg` settles inside `+/-3 deg`
- `heading.commandWz` returns to `0`
- wheel PWM returns to `0`
- `forward 20` and `backward 20` do not visibly drift orientation
- `rotate 90` and `rotate -90` stop in the right direction

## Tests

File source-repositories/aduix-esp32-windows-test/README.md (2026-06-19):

# Audix ESP32 Windows Bench Firmware

This folder is the Windows-only standalone ESP32 testing sandbox.

Use this project when you want to:

- open the ESP32 code directly in VS Code with PlatformIO on Windows
- build and upload over the normal ESP32 USB cable
- upload a local browser UI into ESP32 SPIFFS
- test the ESP32 without the Pi, ROS, or `micro_ros_agent`
- choose a Wi-Fi GUI workflow or a focused USB serial workflow without mixing them
- exercise IMU, encoders, motor outputs, PID motion commands, safety stop,
  RTOS loop-rate reporting, and DRV stepper lift hardware from isolated bench modes

The Windows sandbox IMU path supports MPU6050 and MPU6500/9250/9255-class
accel/gyro chips for bench testing over USB serial.

Do not use this folder as the final Pi-connected submission. The canonical final
firmware stays here:

- `C:\Users\TiBa\OneDrive\Spring 26\Design 2\audix_wps\microROS\firmware\esp32_low_level`

## Open the correct folder

Open this folder itself in VS Code or PlatformIO:

- `C:\Users\TiBa\Documents\PlatformIO\Projects\audix_esp32_windows_test`

That is the folder containing `platformio.ini`.

## Official PlatformIO environments

Wi-Fi dashboard environments:

- `esp32_wifi_base_dashboard`: browser GUI for PID, IMU, encoders, motors, RTOS, and safety.
- `esp32_wifi_stepper_dashboard`: browser GUI for DRV stepper jog, homing, and GPIO4 limit switch.

USB serial-only environments:

- `esp32_serial_pid`: terminal menu for PID/base motion testing.
- `esp32_serial_stepper`: terminal menu for stepper jog, homing, and limit switch testing.
- `esp32_serial_imu_encoder`: terminal menu for IMU and encoder feedback testing.

Compatibility aliases still exist:

- `esp32dev` maps to `esp32_wifi_base_dashboard`.
- `esp32_stepper_wifi` maps to `esp32_wifi_stepper_dashboard`.

## Wi-Fi dashboard workflow

Flash the base dashboard:

```powershell
cd C:\Users\TiBa\Documents\PlatformIO\Projects\audix_esp32_windows_test
pio run -e esp32_wifi_base_dashboard -t upload --upload-port COM10
pio run -e esp32_wifi_base_dashboard -t uploadfs --upload-port COM10
```

Flash the stepper dashboard:

```powershell
cd C:\Users\TiBa\Documents\PlatformIO\Projects\audix_esp32_windows_test
pio run -e esp32_wifi_stepper_dashboard -t upload --upload-port COM10
pio run -e esp32_wifi_stepper_dashboard -t uploadfs --upload-port COM10
```

Then connect to:

- SSID: `AudixBench-ESP32`
- password: `audixbench123`
- browser UI: `http://192.168.4.1/`

For the exact ESP32-only IMU, encoder, motor, RPM, movement, and PID test
sequence, use:

- `docs\esp32_standalone_test_runbook_with_imu.md`

The base dashboard is a simple HTTP-only GUI with live IMU fields, odometry,
encoder/RPM/PWM fields, movement buttons, visual PWM/RPM controls, runtime
`Kp`/`Ki`/`Kd` PID tuning, and a compact raw ESP32 log.

Useful dashboard APIs:

- `http://192.168.4.1/api/ping`
- `http://192.168.4.1/api/state`
- `http://192.168.4.1/api/history`
- `http://192.168.4.1/api/command?line=status`

## Base motor and encoder wiring

Keep motor power disconnected for the first boot after flashing. The base
dashboard uses two-input H-bridge motor control, so `stop` drives both inputs
LOW for each motor.

Wheel order in firmware is `FL, FR, RL, RR`.

This base dashboard mapping intentionally conflicts with the stepper dashboard
on some GPIOs. Flash and wire only one dashboard mode at a time.

| Wheel | Motor label | Motor GPIOs | Encoder label | Encoder GPIOs |
| --- | --- | --- | --- | --- |
| Front Left | MOTD | `17, 18` | ENC2 | `34, 35` |
| Front Right | MOTB | `13, 19` | ENC3 | `33, 32` |
| Rear Left | MOTC | `4, 16` | ENC1 | `39, 36` |
| Rear Right | MOTA | `27, 14` | ENC4 | `25, 26` |

Safe bring-up order:

1. Flash `esp32_wifi_base_dashboard` and `uploadfs`.
2. Boot with motor power disconnected and confirm the Wi-Fi dashboard appears.
3. Run `status`, `encoders zero`, and `encoders on`, then rotate each wheel by hand.
4. Put the robot on blocks before applying motor power.
5. Run `stop`, `enable off`, then test all motors with `motors all 0.30 1.0`.
6. Test one wheel at a time with `motor fl 0.30 1.0`, `motor fr 0.30 1.0`, `motor rl 0.30 1.0`, and `motor rr 0.30 1.0`.
7. Only after wheel order and encoder feedback are correct, run low-power `pidx`, `pidy`, and `pidyaw` tests.

## USB serial workflow

Flash one focused terminal bench:

```powershell
cd C:\Users\TiBa\Documents\PlatformIO\Projects\audix_esp32_windows_test
pio run -e esp32_serial_pid -t upload --upload-port COM10
pio device monitor -p COM10 -b 115200
```

Other serial benches:

```powershell
pio run -e esp32_serial_stepper -t upload --upload-port COM10
pio run -e esp32_serial_imu_encoder -t upload --upload-port COM10
```

Serial-only firmware prints `[wifi] disabled...` and does not create `AudixBench-ESP32`.

## Stepper wiring

- ESP32 `GPIO26` -> DRV `STEP`
- ESP32 `GPIO25` -> DRV `DIR`
- ESP32 `GPIO27` -> DRV `EN`
- ESP32 `GPIO4` -> one side of the home switch
- other side of the home switch -> `GND`
- ESP32 `GND` -> driver logic `GND`
- ESP32 `3V3` -> driver logic VDD only if the breakout exposes logic VDD and accepts 3.3 V logic
- motor supply stays on the driver's own motor-power input
- common ground between ESP32 and driver is required

The stepper variant assumes:

- `EN` is active-low
- the home switch is NO-to-GND and active-low
- `stepper home ...` moves in the configured home direction until the switch is hit

## Dashboard focus

The base Wi-Fi dashboard prioritizes standalone base bring-up:

- IMU scan/status/stream checks
- encoder zero, one-shot, and stream checks
- raw PWM motor checks
- closed-loop wheel RPM checks
- centimeter/degree movement commands
- runtime PID tuning commands
- raw ESP32 log and manual command input

The stepper dashboard remains a separate firmware mode for DRV stepper jog,
homing, and GPIO4 limit-switch tests.

## Serial commands

The serial environments show focused menus. Useful examples:

- PID serial: `status`, `enable on`, `encoders on`, `pidx 0.10 2.0`, `pidy 0.10 2.0`, `pidyaw 0.40 2.0`, `stop`, `enable off`.
- Stepper serial: `status`, `switch`, `enable on`, `jog up 400 2.0`, `jog down 400 2.0`, `home 250 12.0`, `stop`, `enable off`.
- IMU/encoder serial: `i2cscan`, `imu on`, `encoders on`, `rtos on`, `status`, `stop`.

## What this project does not do

- it does not subscribe to `/cmd_vel` or `/robot_enable`
- it does not publish `/odom`, `/imu`, or `/limit_switch` into ROS
- it does not require the Pi or Ubuntu

Those behaviors remain in the final firmware folder only.

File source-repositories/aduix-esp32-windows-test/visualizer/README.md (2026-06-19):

# Audix Stable Base Bench GUI

This folder is uploaded into ESP32 SPIFFS and served directly by the Windows
sandbox firmware.

The active page is intentionally simple:

- stable HTTP polling through `/api/state`
- live IMU yaw, gyro, and accel values
- live odometry x/y/yaw and vx/vy/wz values
- live encoder, RPM, target RPM, and PWM table
- visual PWM and RPM controls
- visual runtime PID tuning for `wheel`, `x`, `y`, and `yaw/z`
- movement buttons for forward, backward, rotate CCW, and rotate CW
- compact raw log
- manual command input

## Flash and open

Use the base dashboard for encoder and PID testing:

```powershell
cd C:\Users\TiBa\Documents\PlatformIO\Projects\audix_esp32_windows_test
pio run -e esp32_wifi_base_dashboard -t upload --upload-port COM10
pio run -e esp32_wifi_base_dashboard -t uploadfs --upload-port COM10
```

Then connect to:

- SSID: `AudixBench-ESP32`
- password: `audixbench123`
- browser: `http://192.168.4.1/`

Useful direct API checks:

```text
http://192.168.4.1/api/ping
http://192.168.4.1/api/state
```

## Encoder first

Start with motor power disconnected:

```text
mode
status
encoders zero
encoders once
encoders on
```

Rotate each wheel by hand and confirm:

- Front Left changes FL / ENC2 / GPIO `34,35`
- Front Right changes FR / ENC3 / GPIO `33,32`
- Rear Left changes RL / ENC1 / GPIO `39,36`
- Rear Right changes RR / ENC4 / GPIO `25,26`

## PID after encoder and single-wheel checks

Keep the robot on blocks:

```text
encoders zero
motors all max 1.0
encoders once
motor fl max 1.0
encoders once
motor fr max 1.0
encoders once
motor rl max 1.0
encoders once
motor rr max 1.0
encoders once
rpm fl 60 2.0
rpm fr 60 2.0
rpm rl 60 2.0
rpm rr 60 2.0
rpms all 60 2.0
rpms all -60 2.0
encoders on
forward 20
encoders once
backward 20
encoders once
rotate 90
encoders once
rotate -90
encoders once
```

PWM is open-loop and uses commands such as:

```text
motor fl 0.30 1.0
motors all max 1.0
```

RPM is closed-loop through encoder feedback and the wheel PID:

```text
rpm fl 60 2.0
rpms all -60 2.0
```

PID values can be changed from the GUI or by command:

```text
pid show
pid wheel 1.20 0.80 0.05
pid x 0.80 0.00 0.02
pid y 0.80 0.00 0.02
pid yaw 1.10 0.00 0.03
```

The one-argument movement commands mean:

```text
forward 20   -> move forward about 20 cm
backward 20  -> move backward about 20 cm
rotate 90    -> rotate counter-clockwise about 90 degrees
rotate -90   -> rotate clockwise about 90 degrees
```

The old velocity/time debug commands are still available:

```text
enable on
forward 0.05 1.0
stop
encoders once
enable on
strafe 0.05 1.0
stop
encoders once
imu on
enable on
rotate 0.20 1.0
stop
encoders once
enable off
```

Use `quiet` any time the serial log is too noisy. It turns off `encoders`, `imu`,
and `rtos` streams without changing the current motor state. Use `stop` if any
wheel moves unexpectedly; it disables motion, turns streams off, and forces motor
outputs low.

If Wi-Fi fails, use VS Code or PlatformIO Serial Monitor:

```powershell
pio device monitor -p COM10 -b 115200
```

## IMU quick test

Use the IMU panel before motor testing:

```text
i2cscan
status
imu on
```

Expected:

- `i2cscan` finds `0x68`
- `status` reports `imuHealthy=yes`
- tilt changes accel
- rotation spikes gyro
- Z rotation changes yaw

Stop the stream with:

```text
imu off
```

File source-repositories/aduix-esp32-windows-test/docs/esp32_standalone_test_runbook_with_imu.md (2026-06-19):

# ESP32 Standalone Test Runbook With IMU

Use this runbook for ESP32-only testing from Windows/VS Code. It tests the
base Wi-Fi dashboard firmware, IMU, encoders, raw motors, RPM control, movement
commands, and PID velocity debug commands without the Pi or ROS.

Do not use this runbook with the stepper dashboard firmware.

## 1. Flash the correct firmware

```powershell
cd "C:\Users\TiBa\Documents\PlatformIO\Projects\audix_esp32_windows_test"
pio run -e esp32_wifi_base_dashboard
pio run -e esp32_wifi_base_dashboard -t upload --upload-port COM10
pio run -e esp32_wifi_base_dashboard -t uploadfs --upload-port COM10
```

If the ESP32 is not on `COM10`, run:

```powershell
pio device list
```

If upload gives a boot-mode or connect error, hold `BOOT`, start upload again,
and release `BOOT` once uploading starts.

## 2. First boot check

Keep motor power disconnected for the first boot. Open the serial fallback:

```powershell
pio device monitor -p COM10 -b 115200
```

Expected boot lines:

```text
[mode] transport=wifi subsystem=base_dashboard
[wifi] hotspot ready
```

If the ESP32 reboots or reports brownout, disconnect motor power and debug
power/wiring before continuing.

## 3. Open the Wi-Fi dashboard

Connect the laptop to:

```text
SSID: AudixBench-ESP32
Password: audixbench123
```

Open:

```text
http://192.168.4.1/?v=stable-pid
```

No internet is needed. If the page is missing, rerun:

```powershell
pio run -e esp32_wifi_base_dashboard -t uploadfs --upload-port COM10
```

If the old page appears, press `Ctrl + F5`.

Direct API checks:

```text
http://192.168.4.1/api/ping
http://192.168.4.1/api/state
```

## 4. Safety reset first

Send:

```text
stop
quiet
status
```

Expected:

```text
[status] emergency stop applied; streams off; motor pins low.
```

## 5. IMU test

IMU wiring:

```text
ESP32 GPIO21 -> IMU SDA
ESP32 GPIO22 -> IMU SCL
ESP32 3V3    -> IMU VCC
ESP32 GND    -> IMU GND
```

Send:

```text
i2cscan
status
imu on
```

Expected:

```text
i2cscan finds 0x68
status shows imuHealthy=yes
[imu] yaw=... gyro=(...) accel=(...)
```

Physical checks:

```text
Tilt board        -> accel values change
Rotate board      -> gyro values spike
Rotate around Z   -> yaw changes
Keep board still  -> gyro near zero, yaw mostly stable
```

Stop the stream:

```text
imu off
```

If `0x68` does not appear in `i2cscan`, check power, SDA/SCL, GND, and
AD0/address wiring.

## 6. Encoder test before motor power

Keep motor power disconnected if possible, or keep the robot fully lifted on
blocks. Send:

```text
stop
encoders zero
encoders on
```

Expected mapping:

```text
Front Left  -> FL row changes -> ENC2 -> GPIO34, GPIO35
Front Right -> FR row changes -> ENC3 -> GPIO33, GPIO32
Rear Left   -> RL row changes -> ENC1 -> GPIO39, GPIO36
Rear Right  -> RR row changes -> ENC4 -> GPIO25, GPIO26
```

Use this for one clean reading:

```text
encoders once
```

If the wrong row changes, fix encoder wiring or mapping before motor/PID tests.

## 7. Raw motor test

Only do this with the robot on blocks.

```text
stop
encoders zero
encoders once
motors all max 1.0
encoders once
motors all -1.00 1.0
encoders once
```

Then one wheel at a time:

```text
motor fl max 1.0
encoders once
motor fr max 1.0
encoders once
motor rl max 1.0
encoders once
motor rr max 1.0
encoders once
```

Expected:

```text
motor fl -> only front-left wheel moves and FL count changes
motor fr -> only front-right wheel moves and FR count changes
motor rl -> only rear-left wheel moves and RL count changes
motor rr -> only rear-right wheel moves and RR count changes
```

If one-wheel commands move the wrong wheel, stop and debug motor GPIO
wiring/mapping before PID.

## 8. RPM test before distance movement

RPM uses encoders and wheel PID:

```text
stop
encoders zero
encoders on
rpm fl 60 2.0
rpm fr 60 2.0
rpm rl 60 2.0
rpm rr 60 2.0
rpms all 60 2.0
rpms all -60 2.0
stop
```

Expected:

```text
single-wheel RPM moves only the selected wheel
all-wheel RPM updates measured RPM in the GUI
```

If raw PWM works but RPM does not, debug encoder sign/direction or PID tuning.

## 9. Forward, backward, and rotate test

Only continue after raw motor and encoder tests look correct.

Inspect or adjust runtime PID values first:

```text
pid show
pid wheel 1.20 0.80 0.05
pid x 0.80 0.00 0.02
pid yaw 1.10 0.00 0.03
```

```text
stop
encoders zero
encoders on
forward 20
encoders once
backward 20
encoders once
rotate 90
encoders once
rotate -90
encoders once
stop
```

Meaning:

```text
forward 20   -> move forward about 20 cm
backward 20  -> move backward about 20 cm
rotate 90    -> rotate counter-clockwise 90 degrees
rotate -90   -> rotate clockwise 90 degrees
```

Expected result logs:

```text
[move] axis=x target=20.0cm measured=...cm error=...cm
[move] axis=yaw target=90.0deg measured=...deg error=...deg
```

If the robot moves in the wrong direction, fix motor direction, wheel order, or
mecanum orientation before tuning PID.

## 10. PID velocity debug test

Only use this after movement commands behave directionally.

```text
stop
encoders zero
encoders on
imu on
pidx 0.05 1.0
stop
encoders once
pidy 0.05 1.0
stop
encoders once
pidyaw 0.20 1.0
stop
encoders once
imu off
encoders off
stop
```

Expected:

```text
pidx 0.05 1.0    -> odom vx changes most
pidy 0.05 1.0    -> odom vy changes most
pidyaw 0.20 1.0  -> odom wz changes and IMU yaw/gyro-z changes
```

## Command meaning

```text
motor fl max 1.0 -> front-left only, 100% raw PWM, 1 second
motor fl 0.30 1.0 -> front-left only, 30% raw PWM, 1 second
rpm fl 60 2.0 -> front-left wheel, 60 RPM target, 2 seconds, closed loop
pidx 0.05 1.0 -> 0.05 m/s chassis X velocity target, 1 second
```

## Stop conditions

Do not continue if:

```text
motor spins immediately after boot
stop does not force motors low
wrong wheel moves during single-wheel test
encoder count changes on the wrong row
IMU i2cscan does not find 0x68
ESP32 keeps rebooting or browning out
```

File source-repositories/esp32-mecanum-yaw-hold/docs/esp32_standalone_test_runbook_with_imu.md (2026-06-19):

# ESP32 Standalone IMU Runbook

This is the IMU-focused bring-up runbook for the yaw-hold bench project.

Use this folder:

```powershell
cd "C:\Users\TiBa\Documents\PlatformIO\Projects\esp32_mecanum_yaw_hold"
```

## Flash

```powershell
pio run -e esp32_wifi_base_dashboard
pio run -e esp32_wifi_base_dashboard -t buildfs
pio run -e esp32_wifi_base_dashboard -t upload --upload-port COM10
pio run -e esp32_wifi_base_dashboard -t uploadfs --upload-port COM10
```

If `COM10` is wrong:

```powershell
pio device list
```

## Open

```text
SSID: AudixBench-ESP32
Password: audixbench123
URL: http://192.168.4.1/
```

## IMU Wiring

```text
GPIO21 -> SDA
GPIO22 -> SCL
3V3    -> VCC
GND    -> GND
```

Expected I2C address is `0x68`.

The driver accepts these WHO_AM_I values:

- `0x68`: MPU6050
- `0x70`: MPU6500
- `0x71`: MPU9250
- `0x73`: MPU9255

## IMU Commands

```text
i2cscan
imu cal
imu zero
imu reset
imu on
imu off
status
```

Meanings:

- `imu cal`: recalibrate gyro bias while the robot is still.
- `imu zero`: set the current yaw angle to zero without changing gyro bias.
- `imu reset`: run bias calibration, then zero yaw.
- `imu on`: print IMU stream lines.
- `imu off`: stop IMU stream lines.

Do not run `imu cal` while motors are moving. The firmware refuses calibration
if command velocity, measured wheel speed, or PWM output indicate motion.

## Quick IMU Validation

```text
stop
i2cscan
imu cal
imu zero
status
imu on
```

Pass:

- `i2cscan` finds `0x68`
- `status` shows `imuHealthy=yes`
- tilting changes accel values
- rotating changes gyro values
- rotating around Z changes yaw
- keeping the robot still leaves gyro Z near zero

Stop the stream:

```text
imu off
```

## Yaw Hold Validation

```text
stop
imu cal
imu zero
encoders zero
yawhold zero
```

Twist the robot by hand and release.

Pass:

- heading error returns toward `0 deg`
- heading error finishes inside `+/-3 deg`
- `heading.commandWz` returns to `0`
- `heading.phaseName` becomes `settled`
- wheel PWM returns to `0`
- no repeated ticks are heard when settled

More complete test instructions are in:

- `docs/yaw_hold_test_procedure.md`
- `docs/tuning_guide.md`

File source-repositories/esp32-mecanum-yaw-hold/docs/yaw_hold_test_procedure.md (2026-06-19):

# Yaw Hold Test Procedure

Use this procedure with the robot lifted on blocks until the RPM and stop tests
pass. Do not run these tests on the floor until wheel direction, encoder mapping,
and stop behavior are correct.

## Build And Flash

```powershell
cd "C:\Users\TiBa\Documents\PlatformIO\Projects\esp32_mecanum_yaw_hold"
pio run -e esp32_wifi_base_dashboard
pio run -e esp32_wifi_base_dashboard -t buildfs
pio run -e esp32_wifi_base_dashboard -t upload --upload-port COM10
pio run -e esp32_wifi_base_dashboard -t uploadfs --upload-port COM10
```

Open the GUI:

```text
SSID: AudixBench-ESP32
Password: audixbench123
URL: http://192.168.4.1/
```

## First Boot

Run:

```text
stop
quiet
status
```

Pass:

- status prints `imuHealthy=yes` after the IMU is initialized
- `cmd=(0, 0, 0)`
- all wheel PWM values are `0`

## IMU Setup

Keep the robot completely still.

```text
i2cscan
imu cal
imu zero
status
```

Pass:

- `i2cscan` finds `0x68`
- `imu cal` reports calibration ok
- `imu zero` sets yaw near `0 deg`
- rotating the robot around Z changes IMU yaw in the GUI

If pressing zero twice used to help, this split is the replacement:

- `imu cal`: estimates gyro bias while still
- `imu zero`: changes the yaw reference only
- `yawhold zero`: zeros yaw and captures `0 deg` as the heading target
- `yawhold on`: captures the current heading target for general hold control

## Encoder And RPM Validation

```text
encoders zero
encoders on
rpm fl 60 2.0
rpm fr 60 2.0
rpm rl 60 2.0
rpm rr 60 2.0
rpms all 60 2.0
rpms all -60 2.0
stop
```

Pass:

- each single-wheel command moves only the selected wheel
- each selected encoder row changes
- measured RPM follows target RPM with no runaway
- `stop` forces PWM to `0`

Fail fast:

- wrong row changes: fix encoder mapping before yaw tests
- raw motion exists but RPM fails: check encoder sign/direction and wheel PID
- wheel keeps ticking after `stop`: stop testing and inspect motor output state

## Still Yaw-Hold Test

```text
stop
imu cal
encoders zero
yawhold zero
```

Twist the robot by hand by about 5 to 15 degrees and release.

Pass:

- `heading.phaseName` changes to `hold_active`
- `heading.yawErrorDeg` moves toward `0` and finishes inside `+/-3 deg`
- `heading.commandWz` has the correct sign and then returns to `0`
- wheel target RPM becomes nonzero while outside `+/-3 deg`
- wheel target RPM returns to `0` when settled
- `heading.phaseName` becomes `settled`
- all wheel PWM values return to `0`
- there are no repeated audible ticks once settled

Fail sign check in under 2 minutes:

1. Run `yawhold zero`.
2. Twist the robot counter-clockwise by hand and hold it.
3. `heading.yawErrorDeg` should show the target is behind the robot.
4. Release it. The first commanded correction must rotate it back toward zero.
5. If it rotates farther away, the yaw correction sign or wheel mixing sign is wrong.

## Straight-Line Test

```text
stop
imu cal
imu zero
encoders zero
forward 20
```

Pass:

- X odometry moves toward about `20 cm`
- yaw error stays small during motion
- when X finishes, heading hold remains active at the original yaw
- after settling, `command.wz`, `heading.commandWz`, wheel targets, and PWM return to zero

Then run:

```text
backward 20
```

Pass criteria are the same, with X moving negative/back toward the starting point.

## Rotation Test

```text
rotate 90
rotate -90
```

Pass:

- `rotate 90` turns counter-clockwise
- `rotate -90` turns clockwise
- yaw error handles wrap around `+/-180`
- final PWM returns to zero

## What To Record

For each failed run, record:

- command sent
- `heading.phaseName`
- `heading.targetYawDeg`
- `heading.yawErrorDeg`
- `heading.commandWz`
- `imu.gyroZ`
- wheel target RPM, measured RPM, and PWM

## Copy-Ready GUI Commands

Paste/send one line at a time through the GUI manual command input.

Clean setup:

```text
stop
yawhold off
quiet
pid wheel 1.20 0.80 0.05
pid yaw 2.00 0.00 0.06
imu cal
yawhold zero
```

If return is too weak:

```text
pid yaw 3.00 0.00 0.08
yawhold zero
```

If it hunts or vibrates:

```text
pid yaw 1.50 0.00 0.08
yawhold zero
```

If it turns the wrong way:

```text
stop
yawhold off
```

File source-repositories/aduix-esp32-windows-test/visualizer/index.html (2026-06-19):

Audix ESP32 sandbox

# Stable Base Bench

HTTP-only GUI for movement, PWM/RPM, IMU, odometry, and PID tuning.

Connecting mode: waiting http://192.168.4.1

STOP Enable Disable Status Quiet Encoder Zero Encoders On IMU On

Live odometry

## Position and movement

x cm0.00

y cm0.00

yaw deg0.00

vx0.000

vy0.000

wz0.000

Live IMU

## Yaw and motion sensor

healthunknown

yaw deg0.00

gyro z0.000

accel x0.000

accel y0.000

accel z0.000

I2C Scan IMU On IMU Off

Movement

## Forward, backward, and rotation

Forward/backward use encoder odometry and IMU yaw hold. Rotation uses yaw/Z PID.

Distance cm Forward Backward Angle degrees Rotate CCW Rotate CW

Wheel feedback

## Encoders, RPM, and PWM

Wheel | Count | RPM | Target RPM | rad/s | PWM
FL | 0 | 0.000 | 0.000 | 0.000 | 0.000
FR | 0 | 0.000 | 0.000 | 0.000 | 0.000
RL | 0 | 0.000 | 0.000 | 0.000 | 0.000
RR | 0 | 0.000 | 0.000 | 0.000 | 0.000

Raw PWM

## Open-loop motor power

Wheel PWM Duration s

Send PWM Reverse PWM Max PWM

Closed-loop RPM

## Wheel speed PID

Wheel RPM Duration s

Send RPM Reverse RPM

Runtime PID tuning

## Kp, Ki, Kd controls

Wheel tunes RPM. X tunes forward/backward distance. Y is prepared for strafe. Yaw/Z tunes rotation and straight-line heading hold.

PID Show

Raw log

## Command feedback

Clear Copy

Send

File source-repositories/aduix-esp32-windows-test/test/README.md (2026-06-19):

# Firmware Tests

This directory is reserved for low-level unit or hardware-abstraction tests.

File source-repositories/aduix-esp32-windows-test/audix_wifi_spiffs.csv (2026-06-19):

# Name | Type | SubType | Offset | Size | Flags
nvs | data | nvs | 0x9000 | 0x5000
otadata | data | ota | 0xe000 | 0x2000
app0 | app | ota_0 | 0x10000 | 0x280000
spiffs | data | spiffs | 0x290000 | 0x170000

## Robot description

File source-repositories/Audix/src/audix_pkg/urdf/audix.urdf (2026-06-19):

<?xml version="1.0" encoding="utf-8"?>
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
<robot name="audix">
  <link name="base_link">
    <inertial>
      <origin xyz="-0.165425609192592 -0.149974396919815 0.0555112241125014" rpy="0 0 0" />
      <mass value="2.23789814285684" />
      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
    </inertial>
    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
  </link>
  <link name="front_left_wheel_link">
    <inertial>
      <origin xyz="2.17268698310402E-06 2.05342648856854E-07 -0.00553115532802828" rpy="0 0 0" />
      <mass value="0.131907084296385" />
      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
    </inertial>
    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
  </link>
  <joint name="front_left_wheel_joint" type="continuous">
    <origin xyz="-0.250000000005374 -0.307389999999985 0.024999999989585" rpy="1.57079632679489 0 0" />
    <parent link="base_link" />
    <child link="front_left_wheel_link" />
    <axis xyz="0 0 -1" />
  </joint>
  <link name="front_right_wheel_link">
    <inertial>
      <origin xyz="9.66289620374372E-07 -2.18301833003476E-06 0.005591563250399" rpy="0 0 0" />
      <mass value="0.131907400590731" />
      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
    </inertial>
    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
  </link>
  <joint name="front_right_wheel_joint" type="continuous">
    <origin xyz="-0.250000000005375 0.00739000000001477 0.0249999999895845" rpy="1.57079632679489 0 0" />
    <parent link="base_link" />
    <child link="front_right_wheel_link" />
    <axis xyz="0 0 1" />
  </joint>
  <link name="back_right_wheel_link">
    <inertial>
      <origin xyz="3.93598461267963E-07 -2.20615013937081E-06 0.00553103387698972" rpy="0 0 0" />
      <mass value="0.131907129758154" />
      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
    </inertial>
    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
  </link>
  <joint name="back_right_wheel_joint" type="continuous">
    <origin xyz="-0.0700000000053771 0.00739000000001488 0.0249999999906142" rpy="1.57079632679489 0 0" />
    <parent link="base_link" />
    <child link="back_right_wheel_link" />
    <axis xyz="0 0 1" />
  </joint>
  <link name="back_left_wheel_link">
    <inertial>
      <origin xyz="2.27704030925091E-06 3.56143494868733E-07 -0.00559151540708869" rpy="0 0 0" />
      <mass value="0.131907545752213" />
      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
    </inertial>
    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
  </link>
  <joint name="back_left_wheel_joint" type="continuous">
    <origin xyz="-0.0700000000053768 -0.307389999999987 0.024999999990612" rpy="1.57079632679489 0 0" />
    <parent link="base_link" />
    <child link="back_left_wheel_link" />
    <axis xyz="0 0 -1" />
  </joint>
  <link name="scissors_lift_base">
    <inertial>
      <origin xyz="0.0640804372939909 6.00038682641024E-06 0.0414333132682887" rpy="0 0 0" />
      <mass value="0.240484568927395" />
      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
    </inertial>
    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
  </link>
  <joint name="scissors_lift_base_fix" type="fixed">
    <origin xyz="-0.310000000005584 -0.150000000000003 0.0124999999899842" rpy="0 0 0" />
    <parent link="base_link" />
    <child link="scissors_lift_base" />
    <axis xyz="0 0 0" />
  </joint>
  <link name="bottom_stud_link">
    <inertial>
      <origin xyz="-9.6601817455369E-07 7.19407882932011E-07 -1.3007363775519E-06" rpy="0 0 0" />
      <mass value="0.00137057236420401" />
      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
    </inertial>
    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
  </link>
  <joint name="bottom_stud_joint" type="prismatic">
    <origin xyz="0.137801664111862 -0.000349280592105594 0.0424989715630968" rpy="3.14159265358979 1.5707963267949 0" />
    <parent link="scissors_lift_base" />
    <child link="bottom_stud_link" />
    <axis xyz="0 0 1" />
    <limit lower="0" upper="0" effort="0" velocity="0" />
  </joint>
  <link name="right_link1">
    <inertial>
      <origin xyz="0.0589015692763848 0.0114282604442705 -1.94289029309402E-14" rpy="0 0 0" />
      <mass value="0.00615413438956677" />
      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
    </inertial>
    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
  </link>
  <joint name="right_joint1" type="revolute">
    <origin xyz="0 -0.0428492805921222 0" rpy="1.5707963267949 -1.5707963267949 0" />
    <parent link="bottom_stud_link" />
    <child link="right_link1" />
    <axis xyz="0 0 1" />
    <limit lower="0" upper="0" effort="0" velocity="0" />
  </joint>
  <link name="right_link4">
    <inertial>
      <origin xyz="0.0589015692765562 0.0114282604443096 2.1094237467878E-14" rpy="0 0 0" />
      <mass value="0.00615413438956673" />
      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
    </inertial>
    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
  </link>
  <joint name="right_joint4" type="revolute">
    <origin xyz="0.117803138552813 0.0228565208880633 -0.00499999999999967" rpy="3.14159265358979 0 3.14159265358979" />
    <parent link="right_link1" />
    <child link="right_link4" />
    <axis xyz="0 0 1" />
    <limit lower="0" upper="0" effort="0" velocity="0" />
  </joint>
  <link name="right_link5">
    <inertial>
      <origin xyz="0.0589015692761234 0.0110362235597465 0.00296764322724363" rpy="0 0 0" />
      <mass value="0.00615413438956677" />
      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
    </inertial>
    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
  </link>
  <joint name="right_joint5" type="revolute">
    <origin xyz="0.117803138552815 0.022856520887972 -0.00500000000000012" rpy="2.87890613213286 0 3.14159265358978" />
    <parent link="right_link4" />
    <child link="right_link5" />
    <axis xyz="0 0.259675848455465 -0.965695839138253" />
    <limit lower="0" upper="0" effort="0" velocity="0" />
  </joint>
  <link name="left_link1">
    <inertial>
      <origin xyz="0.0589015692763918 0.0114282604442722 -2.29816166097407E-14" rpy="0 0 0" />
      <mass value="0.0061541343895667" />
      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
    </inertial>
    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
  </link>
  <joint name="left_joint1" type="revolute">
    <origin xyz="0 0.0421507194078778 0" rpy="1.5707963267949 -1.5707963267949 0" />
    <parent link="bottom_stud_link" />
    <child link="left_link1" />
    <axis xyz="0 0 1" />
    <limit lower="0" upper="0" effort="0" velocity="0" />
  </joint>
  <link name="left_link4">
    <inertial>
      <origin xyz="0.058901569276552 0.0114282604443232 2.28705943072782E-14" rpy="0 0 0" />
      <mass value="0.00615413438956676" />
      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
    </inertial>
    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
  </link>
  <joint name="left_joint4" type="revolute">
    <origin xyz="0.117803138552813 0.0228565208880835 0.00499999999999956" rpy="3.14159265358979 0 3.14159265358979" />
    <parent link="left_link1" />
    <child link="left_link4" />
    <axis xyz="0 0 1" />
    <limit lower="0" upper="0" effort="0" velocity="0" />
  </joint>
  <link name="left_link5">
    <inertial>
      <origin xyz="0.0589015692761248 0.0114282604444132 -2.16493489801906E-14" rpy="0 0 0" />
      <mass value="0.00615413438956676" />
      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
    </inertial>
    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
  </link>
  <joint name="left_joint5" type="revolute">
    <origin xyz="0.117803138552813 0.0228565208880058 0.00499999999999967" rpy="3.14159265358979 0 3.14159265358979" />
    <parent link="left_link4" />
    <child link="left_link5" />
    <axis xyz="0 0 -1" />
    <limit lower="0" upper="0" effort="0" velocity="0" />
  </joint>
  <link name="camera_link">
    <inertial>
      <origin xyz="-0.0682144048132187 0.0215672397949688 -0.0429610406081863" rpy="0 0 0" />
      <mass value="0.354470228585855" />
      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
    </inertial>
    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
  </link>
  <joint name="camera_joint" type="revolute">
    <origin xyz="0.117803138552453 0.0228565208887948 0.0849999999999819" rpy="0 0 0" />
    <parent link="left_link5" />
    <child link="camera_link" />
    <axis xyz="0 0 -1" />
    <limit lower="0" upper="0" effort="0" velocity="0" />
  </joint>
  <link name="right_link2">
    <inertial>
      <origin xyz="0.0589015692764303 0.0114282604443792 1.93178806284777E-14" rpy="0 0 0" />
      <mass value="0.00615413438956677" />
      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
    </inertial>
    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
  </link>
  <joint name="right_joint2" type="continuous">
    <origin xyz="0.0200000000000368 0.0375000000000166 0.0424999999993435" rpy="1.5707963267949 0 0" />
    <parent link="scissors_lift_base" />
    <child link="right_link2" />
    <axis xyz="0 0 1" />
  </joint>
  <link name="right_link3">
    <inertial>
      <origin xyz="0.0589015692762507 0.0114282604443728 -1.98729921407903E-14" rpy="0 0 0" />
      <mass value="0.00615413438956667" />
      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
    </inertial>
    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
  </link>
  <joint name="right_joint3" type="revolute">
    <origin xyz="0.117803138552811 0.0228565208881228 -0.00500000000000023" rpy="3.14159265358979 0 3.14159265358979" />
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

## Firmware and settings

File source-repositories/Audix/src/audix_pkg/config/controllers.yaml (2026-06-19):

controller_manager:
  ros__parameters:
    update_rate: 50

    joint_state_broadcaster:
      type: joint_state_broadcaster/JointStateBroadcaster

    diff_drive_controller:
      type: diff_drive_controller/DiffDriveController

diff_drive_controller:
  ros__parameters:
    left_wheel_names: ['front_left_wheel_joint', 'back_left_wheel_joint']
    right_wheel_names: ['front_right_wheel_joint', 'back_right_wheel_joint']

    wheel_separation: 0.3148
    wheel_radius: 0.05

    wheel_separation_multiplier: 1.0
    left_wheel_radius_multiplier: 1.0
    right_wheel_radius_multiplier: 1.0

    publish_rate: 50.0
    odom_frame_id: odom
    base_frame_id: RobotBody
    pose_covariance_diagonal: [0.001, 0.001, 0.001, 0.001, 0.001, 0.01]
    twist_covariance_diagonal: [0.001, 0.001, 0.001, 0.001, 0.001, 0.01]
    open_loop: true
    enable_odom_tf: true

    cmd_vel_timeout: 0.5
    use_stamped_vel: true

    linear.x.has_velocity_limits: true
    linear.x.has_acceleration_limits: true
    linear.x.has_jerk_limits: false
    linear.x.max_velocity: 1.0
    linear.x.min_velocity: -1.0
    linear.x.max_acceleration: 1.0
    linear.x.max_jerk: 0.0
    linear.x.min_jerk: 0.0

    angular.z.has_velocity_limits: true
    angular.z.has_acceleration_limits: true
    angular.z.has_jerk_limits: false
    angular.z.max_velocity: 1.0
    angular.z.min_velocity: -1.0
    angular.z.max_acceleration: 1.0
    angular.z.min_acceleration: -1.0
    angular.z.max_jerk: 0.0
    angular.z.min_jerk: 0.0

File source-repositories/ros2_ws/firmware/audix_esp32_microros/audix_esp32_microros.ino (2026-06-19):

// Clean mecanum cascaded position controller for the ESP32 Mecanum base.
//
// Clean control rebuild plan:
//   1) Tune one wheel velocity PI clearly.
//   2) Run all four wheel velocity PI loops together.
//   3) Add mecanum body velocity mixing: forward, strafe, rotate.
//   4) Add encoder odometry.
//   5) Add outer position and heading control as cascaded loops.
//
// Research references used for this rebuild:
//   - https://ietresearch.onlinelibrary.wiley.com/doi/full/10.1049/tje2.70006
//   - https://docs.simplefoc.com/angle_cascade_control
//   - https://forum.arduino.cc/t/pid-control-loops/599383
//   - https://robotics.stackexchange.com/questions/90020/how-to-fuse-encoder-ticks-imu-for-odometry
//   - https://docs.wpilib.org/en/stable/docs/software/kinematics-and-odometry/mecanum-drive-odometry.html
//   - https://docs.ros.org/en/rolling/p/robot_localization/configuring_robot_localization.html
//
// Stage 5 of the clean control rebuild:
//   - body-frame forward / strafe / rotate commands
//   - mecanum inverse kinematics -> four wheel RPM targets
//   - all four wheel velocity loops run at the same time
//   - encoder odometry estimates body-frame forward and strafe displacement
//   - outer body-position P loops generate velocity commands
//   - heading uses position error plus gyro-rate damping for clean settling
//   - per-wheel tuned inner velocity PI loops
//   - wheel target scaling preserves direction while respecting RPM limit
//   - PWM saturation with conditional-integration anti-windup
//
// Pi bridge note:
//   This sketch keeps the exact new_pid controller and web GUI. The UART JSON
//   bridge commands are transported by micro-ROS topics instead of raw UART so
//   micro_ros_agent can own the ESP serial link.
//
// This sketch intentionally has no minPWM, feedforward, derivative term,
// slip detector, full EKF, or field-frame pose correction yet.
// Heading control uses IMU yaw. Encoder yaw is kept only as a diagnostic/fallback
// because mecanum wheel slip makes encoder-derived yaw unreliable during turns.

#include <Arduino.h>
#include <WiFi.h>
#include <WebServer.h>
#include <Wire.h>
#include <math.h>
#include <string.h>
#include <freertos/FreeRTOS.h>
#include <freertos/task.h>
#include <freertos/semphr.h>
#include <micro_ros_arduino.h>
#include <rcl/rcl.h>
#include <rcl/error_handling.h>
#include <rclc/rclc.h>
#include <rclc/executor.h>
#include <rmw_microros/rmw_microros.h>
#include <std_msgs/msg/string.h>

struct EncoderPins {
  uint8_t a;
  uint8_t b;
  const char* name;
};

struct MotorPins {
  uint8_t in1;
  uint8_t in2;
  const char* name;
  uint8_t encoderIndex;
  uint8_t ch1;
  uint8_t ch2;
};

struct WheelPiState {
  float integralError;
  float errorRpm;
  float pTerm;
  float iTerm;
  float rawOutput;
  float output;
};

struct BodyPiState {
  float integralError;
  float error;
  float pTerm;
  float iTerm;
  float rawOutputRpm;
  float outputRpm;
};

struct TelemetrySnapshot {
  bool enabled;
  bool timedRunActive;
  bool positionModeActive;
  bool positionTargetReached;
  uint32_t positionMoveId;
  float kp[4];
  float ki[4];
  float positionKp;
  float positionKi;
  float yawKp;
  float yawKi;
  float positionMaxRpm;
  float positionToleranceCm;
  float yawToleranceDeg;
  bool imuOk;
  bool headingUsesImu;
  float imuYawDeg;
  float imuYawRawDeg;
  float encoderYawDeg;
  float imuGyroDps;
  float imuGyroDpsFilt;
  float imuBiasDps;
  float imuCalStdDps;
  bool imuCalValid;
  float loopDtMs;
  uint32_t nowMs;
  uint32_t timedRunId;
  uint32_t timedRunDurationMs;
  uint32_t timedRunElapsedMs;
  float commandForwardRpm;
  float commandStrafeRpm;
  float commandRotateRpm;
  float targetScale;
  int8_t strafeSign;
  int8_t rotateSign;
  int8_t odomForwardSign;
  int8_t odomStrafeSign;
  int8_t odomYawSign;
  float odomForwardScale;
  float odomStrafeScale;
  float odomForwardCm;
  float odomStrafeCm;
  float odomYawDeg;
  float targetForwardCm;
  float targetStrafeCm;
  float targetYawDeg;
  float positionErrorForwardCm;
  float positionErrorStrafeCm;
  float positionErrorYawDeg;
  float positionPTerm[3];
  float positionITerm[3];
  float positionOutputRpm[3];
  float odomWheelCm[4];
  float rawTargetRpm[4];
  float targetRpm[4];
  float appliedTargetRpm[4];
  float rawRpm[4];
  float measuredRpm[4];
  float errorRpm[4];
  float pTerm[4];
  float iTerm[4];
  float rawOutput[4];
  float output[4];
  float integralError[4];
  int16_t pwm[4];
  int16_t hardwarePwm[4];
  int8_t encoderSign[4];
  int8_t motorSign[4];
  int32_t rawCounts[4];
  int32_t signedCounts[4];
};

const char* WHEEL_NAMES[4] = {"BR", "FR", "BL", "FL"};

// Logical motor order is fixed here as BR, FR, BL, FL.
// Calibrated mapping from the clean single-wheel tests:
//   BR -> MOTA / ENC1
//   FR -> MOTB / ENC2
//   BL -> MOTD / ENC4
//   FL -> MOTC / ENC3
EncoderPins encoders[4] = {
    {36, 39, "ENC1 BackRight"},
    {35, 34, "ENC2 FrontRight"},
    {33, 32, "ENC3 FrontLeft"},
    {25, 26, "ENC4 BackLeft"},
};

MotorPins motors[4] = {
    {14, 27, "MOTA BackRight", 0, 0, 1},
    {19, 13, "MOTB FrontRight", 1, 2, 3},
    {18, 17, "MOTD BackLeft", 3, 6, 7},
    {4, 16, "MOTC FrontLeft", 2, 4, 5},
};

// Calibrated order BR, FR, BL, FL.
int8_t encoderSign[4] = {-1, 1, -1, 1};
int8_t motorSign[4] = {1, 1, 1, 1};

volatile int32_t encoderCount[4] = {0, 0, 0, 0};
volatile uint8_t encoderPrevState[4] = {0, 0, 0, 0};

int32_t lastEncoderCount[4] = {0, 0, 0, 0};
int32_t lastOdomSignedCount[4] = {0, 0, 0, 0};
float rawRpm[4] = {0, 0, 0, 0};
float measuredRpm[4] = {0, 0, 0, 0};
float targetRpm[4] = {0, 0, 0, 0};
int16_t pwmCmd[4] = {0, 0, 0, 0};
int16_t hardwarePwmCmd[4] = {0, 0, 0, 0};
WheelPiState piState[4] = {};
BodyPiState positionPi[3] = {};

const char* AP_SSID = "ESP32-MECANUM-POS";
const char* AP_PASS = "position123";

const float COUNTS_PER_WHEEL_REV = 4346.8f;
const float WHEEL_DIAMETER_CM = 9.7f;
const float WHEEL_CIRCUMFERENCE_CM = WHEEL_DIAMETER_CM * PI;
const uint32_t CONTROL_INTERVAL_MS = 20;
const float NOMINAL_DT_S = CONTROL_INTERVAL_MS / 1000.0f;
const float RPM_TARGET_LIMIT = 45.0f;
const float RPM_FILTER_ALPHA = 0.20f;
const uint32_t UART_BAUD = 115200;
const size_t UART_LINE_MAX = 180;
const uint32_t PI_TELEMETRY_INTERVAL_MS = 100;
const uint8_t DEFAULT_LIMIT_STATUS_PIN = 23;
const uint32_t TIMED_RUN_MIN_MS = 250;
const uint32_t TIMED_RUN_MAX_MS = 120000;
const float CMD_VEL_LINEAR_MPS_TO_RPM = 60.0f / (WHEEL_CIRCUMFERENCE_CM / 100.0f);
const float CMD_VEL_ANGULAR_RADPS_TO_RPM = 22.0f;
const uint32_t CMD_VEL_TIMEOUT_MS = 300;
const uint32_t MICRO_ROS_SPIN_MS = 5;
const size_t MICRO_ROS_TELEMETRY_BUFFER = 640;
const uint32_t MICRO_ROS_RECONNECT_PERIOD_MS = 1000;
const uint32_t MICRO_ROS_AGENT_PING_TIMEOUT_MS = 100;
const uint8_t MICRO_ROS_AGENT_PING_ATTEMPTS = 1;

const uint16_t PWM_FREQ = 1000;
const uint8_t PWM_RES_BITS = 8;
const int PWM_MAX = 255;

const uint8_t MPU6050_ADDR = 0x68;
const float MPU6050_GYRO_Z_SCALE = 65.5f;  // LSB/(deg/s) at +-500 dps.
const float MPU6050_GYRO_FILTER_ALPHA = 0.20f;
const float MPU6050_CAL_MAX_STD_DPS = 0.35f;
const float ENCODER_YAW_CM_PER_DEG = 0.30f;
const float YAW_DAMP_RPM_PER_DPS = 0.20f;
const float YAW_CONTROL_DEADBAND_DEG = 2.0f;
const float YAW_SETTLE_RATE_DPS = 3.0f;
const float YAW_NEAR_TARGET_DEG = 15.0f;
const float YAW_NEAR_TARGET_MAX_RPM = 10.0f;
const uint8_t POSITION_SETTLE_TICKS_REQUIRED = 8;

float velocityKp[4] = {15.0f, 15.0f, 15.0f, 15.0f};
float velocityKi[4] = {200.0f, 200.0f, 200.0f, 200.0f};
float commandForwardRpm = 0.0f;
float commandStrafeRpm = 0.0f;
float commandRotateRpm = 0.0f;
float rawTargetRpm[4] = {0, 0, 0, 0};
float targetScale = 1.0f;
int8_t strafeSign = -1;
int8_t rotateSign = 1;
int8_t odomForwardSign = 1;
int8_t odomStrafeSign = -1;
int8_t odomYawSign = 1;
float odomForwardScale = 0.9854f;
float odomStrafeScale = 0.9375f;
float odomForwardCm = 0.0f;
float odomStrafeCm = 0.0f;
float odomYawWheelCm = 0.0f;
float odomWheelCm[4] = {0, 0, 0, 0};
bool positionModeActive = false;
bool positionTargetReached = false;
uint8_t positionSettleTicks = 0;
uint32_t positionMoveId = 0;
float targetForwardCm = 0.0f;
float targetStrafeCm = 0.0f;
float targetYawDeg = 0.0f;
float positionErrorForwardCm = 0.0f;
float positionErrorStrafeCm = 0.0f;
float positionErrorYawDeg = 0.0f;
float positionKp = 100.0f;
float positionKi = 0.0f;
float yawKp = 10.0f;
float yawKi = 0.0f;
float positionMaxRpm = 40.0f;
float positionToleranceCm = 2.0f;
float yawToleranceDeg = 2.0f;
bool imuOk = false;
float imuYawDeg = 0.0f;
float imuYawRawDeg = 0.0f;
float imuGyroDps = 0.0f;
float imuGyroDpsFilt = 0.0f;
float imuBiasDps = 0.0f;
float imuCalStdDps = 0.0f;
bool imuCalValid = false;
bool controllerEnabled = false;
float lastLoopDtMs = CONTROL_INTERVAL_MS;
bool timedRunActive = false;
uint32_t timedRunStartMs = 0;
uint32_t timedRunDurationMs = 3000;
uint32_t timedRunId = 0;

WebServer server(80);
SemaphoreHandle_t stateMutex = nullptr;
SemaphoreHandle_t serialMutex = nullptr;
TaskHandle_t controlTaskHandle = nullptr;
TaskHandle_t webTaskHandle = nullptr;
TaskHandle_t uartTaskHandle = nullptr;
TaskHandle_t piTelemetryTaskHandle = nullptr;
TaskHandle_t microRosTaskHandle = nullptr;

#define STATE_LOCK()   do { if (stateMutex) xSemaphoreTake(stateMutex, portMAX_DELAY); } while (0)
#define STATE_UNLOCK() do { if (stateMutex) xSemaphoreGive(stateMutex); } while (0)
#define SERIAL_LOCK()   do { if (serialMutex) xSemaphoreTake(serialMutex, portMAX_DELAY); } while (0)
#define SERIAL_UNLOCK() do { if (serialMutex) xSemaphoreGive(serialMutex); } while (0)

uint32_t piActiveSeq = 0;
bool piMoveActive = false;
float piMoveStartForwardCm = 0.0f;
float piMoveStartStrafeCm = 0.0f;
float piOdomForwardCm = 0.0f;
float piOdomStrafeCm = 0.0f;
float piLastMoveAngleDeg = 0.0f;
float piLastMoveDistanceCm = 0.0f;
bool piPendingDone = false;
uint32_t piPendingDoneSeq = 0;
uint8_t piPendingDoneCode = 0;

rcl_allocator_t microrosAllocator;
rclc_support_t microrosSupport;
rcl_node_t microrosNode = rcl_get_zero_initialized_node();
rclc_executor_t microrosExecutor = rclc_executor_get_zero_initialized_executor();
rcl_timer_t telemetryTimer = rcl_get_zero_initialized_timer();
rcl_subscription_t moveGoalSub = rcl_get_zero_initialized_subscription();
rcl_publisher_t telemetryJsonPub = rcl_get_zero_initialized_publisher();
std_msgs__msg__String moveGoalMsg;
std_msgs__msg__String telemetryJsonMsg;
char moveGoalBuffer[UART_LINE_MAX];
char telemetryJsonBuffer[MICRO_ROS_TELEMETRY_BUFFER];
bool microrosEntitiesCreated = false;
uint32_t microrosLastConnectAttemptMs = 0;

#define RCSOFTCHECK(fn) do { rcl_ret_t temp_rc = (fn); (void)temp_rc; } while (0)

float wrapAngleDeg(float angle) {
  while (angle > 180.0f) angle -= 360.0f;
  while (angle <= -180.0f) angle += 360.0f;
  return angle;
}

float shortestAngleErrorDeg(float target, float measurement) {
  return wrapAngleDeg(target - measurement);
}

#if defined(ESP_ARDUINO_VERSION_MAJOR) && (ESP_ARDUINO_VERSION_MAJOR >= 3)
void pwmAttachPinCompat(uint8_t pin, uint8_t channelHint) {
  (void)channelHint;
  ledcAttach(pin, PWM_FREQ, PWM_RES_BITS);
}

void pwmWriteCompat(uint8_t pin, uint8_t channelHint, uint32_t duty) {
  (void)channelHint;
  ledcWrite(pin, duty);
}
#else
void pwmAttachPinCompat(uint8_t pin, uint8_t channel) {
  ledcSetup(channel, PWM_FREQ, PWM_RES_BITS);
  ledcAttachPin(pin, channel);
}

void pwmWriteCompat(uint8_t pin, uint8_t channel, uint32_t duty) {
  (void)pin;
  ledcWrite(channel, duty);
}
#endif

bool isInputOnlyPin(uint8_t pin) {
  return pin == 34 || pin == 35 || pin == 36 || pin == 39;
}

void setupEncoderPin(uint8_t pin) {
  pinMode(pin, isInputOnlyPin(pin) ? INPUT : INPUT_PULLUP);
}

void IRAM_ATTR updateEncoder(uint8_t idx) {
  uint8_t state = (digitalRead(encoders[idx].a) << 1) | digitalRead(encoders[idx].b);
  uint8_t prev = encoderPrevState[idx];
  uint8_t transition = (prev << 2) | state;

  switch (transition) {
    case 0b0001:
    case 0b0111:
    case 0b1110:
    case 0b1000:
      encoderCount[idx]++;
      break;
    case 0b0010:
    case 0b0100:
    case 0b1101:
    case 0b1011:
      encoderCount[idx]--;
      break;
    default:
      break;
  }

  encoderPrevState[idx] = state;
}

void IRAM_ATTR isrEnc0A() { updateEncoder(0); }
void IRAM_ATTR isrEnc0B() { updateEncoder(0); }
void IRAM_ATTR isrEnc1A() { updateEncoder(1); }
void IRAM_ATTR isrEnc1B() { updateEncoder(1); }
void IRAM_ATTR isrEnc2A() { updateEncoder(2); }
void IRAM_ATTR isrEnc2B() { updateEncoder(2); }
void IRAM_ATTR isrEnc3A() { updateEncoder(3); }
void IRAM_ATTR isrEnc3B() { updateEncoder(3); }

int32_t readEncoderCount(uint8_t idx) {
  noInterrupts();
  int32_t count = encoderCount[idx];
  interrupts();
  return count;
}

void setMotorPwmSigned(uint8_t wheel, int command) {
  command = constrain(command, -PWM_MAX, PWM_MAX);
  pwmCmd[wheel] = (int16_t)command;

  int hardwareCommand = constrain(command * (int)motorSign[wheel], -PWM_MAX, PWM_MAX);
  hardwarePwmCmd[wheel] = (int16_t)hardwareCommand;

  const MotorPins& motor = motors[wheel];
  if (hardwareCommand > 0) {
    pwmWriteCompat(motor.in1, motor.ch1, (uint32_t)hardwareCommand);
    pwmWriteCompat(motor.in2, motor.ch2, 0);
  } else if (hardwareCommand < 0) {
    pwmWriteCompat(motor.in1, motor.ch1, 0);
    pwmWriteCompat(motor.in2, motor.ch2, (uint32_t)(-hardwareCommand));
  } else {
    pwmWriteCompat(motor.in1, motor.ch1, 0);
    pwmWriteCompat(motor.in2, motor.ch2, 0);
  }
}

void stopAllMotors() {
  for (uint8_t i = 0; i < 4; i++) {
    setMotorPwmSigned(i, 0);
  }
}

void resetPiState(uint8_t wheel) {
  piState[wheel].integralError = 0.0f;
  piState[wheel].errorRpm = 0.0f;
  piState[wheel].pTerm = 0.0f;
  piState[wheel].iTerm = 0.0f;
  piState[wheel].rawOutput = 0.0f;
  piState[wheel].output = 0.0f;
}

void resetAllPiStates() {
  for (uint8_t i = 0; i < 4; i++) {
    resetPiState(i);
  }
}

void resetBodyPiState(uint8_t axis) {
  positionPi[axis].integralError = 0.0f;
  positionPi[axis].error = 0.0f;
  positionPi[axis].pTerm = 0.0f;
  positionPi[axis].iTerm = 0.0f;
  positionPi[axis].rawOutputRpm = 0.0f;
  positionPi[axis].outputRpm = 0.0f;
}

void resetAllBodyPiStates() {
  for (uint8_t axis = 0; axis < 3; axis++) {
    resetBodyPiState(axis);
  }
  positionSettleTicks = 0;
}

void resetEncoderMeasurements() {
  noInterrupts();
  for (uint8_t i = 0; i < 4; i++) {
    encoderCount[i] = 0;
  }
  interrupts();

  for (uint8_t i = 0; i < 4; i++) {
    lastEncoderCount[i] = 0;
    rawRpm[i] = 0.0f;
    measuredRpm[i] = 0.0f;
  }
}

void resetRpmMeasurementsToCurrentCounts() {
  for (uint8_t encoder = 0; encoder < 4; encoder++) {
    lastEncoderCount[encoder] = readEncoderCount(encoder);
  }

  for (uint8_t wheel = 0; wheel < 4; wheel++) {
    rawRpm[wheel] = 0.0f;
    measuredRpm[wheel] = 0.0f;
  }
}

void resetOdometryToCurrentCounts() {
  for (uint8_t wheel = 0; wheel < 4; wheel++) {
    int32_t rawCount = readEncoderCount(motors[wheel].encoderIndex);
    lastOdomSignedCount[wheel] = ((int32_t)encoderSign[wheel]) * rawCount;
    odomWheelCm[wheel] = 0.0f;
  }

  odomForwardCm = 0.0f;
  odomStrafeCm = 0.0f;
  odomYawWheelCm = 0.0f;
}

void updateMeasuredRpm(float dt) {
  if (dt <= 0.0001f) {
    return;
  }

  const float rpmScale = (60.0f / COUNTS_PER_WHEEL_REV) / dt;
  for (uint8_t wheel = 0; wheel < 4; wheel++) {
    uint8_t encoderIndex = motors[wheel].encoderIndex;
    int32_t countNow = readEncoderCount(encoderIndex);
    int32_t delta = countNow - lastEncoderCount[encoderIndex];
    lastEncoderCount[encoderIndex] = countNow;

    rawRpm[wheel] = ((float)encoderSign[wheel]) * ((float)delta) * rpmScale;
    measuredRpm[wheel] += RPM_FILTER_ALPHA * (rawRpm[wheel] - measuredRpm[wheel]);
  }
}

void updateOdometry() {
  float deltaWheelCm[4] = {0, 0, 0, 0};

  for (uint8_t wheel = 0; wheel < 4; wheel++) {
    int32_t rawCount = readEncoderCount(motors[wheel].encoderIndex);
    int32_t signedCount = ((int32_t)encoderSign[wheel]) * rawCount;
    int32_t deltaCount = signedCount - lastOdomSignedCount[wheel];
    lastOdomSignedCount[wheel] = signedCount;

    deltaWheelCm[wheel] = ((float)deltaCount / COUNTS_PER_WHEEL_REV) * WHEEL_CIRCUMFERENCE_CM;
    odomWheelCm[wheel] += deltaWheelCm[wheel];
  }

  // Logical order is BR, FR, BL, FL. This is body-frame dead reckoning.
  odomForwardCm += (deltaWheelCm[0] + deltaWheelCm[1] + deltaWheelCm[2] + deltaWheelCm[3]) * 0.25f;
  odomStrafeCm += (-deltaWheelCm[0] + deltaWheelCm[1] + deltaWheelCm[2] - deltaWheelCm[3]) * 0.25f;
  odomYawWheelCm += (-deltaWheelCm[0] - deltaWheelCm[1] + deltaWheelCm[2] + deltaWheelCm[3]) * 0.25f;
}

bool imuWriteReg(uint8_t reg, uint8_t value) {
  Wire.beginTransmission(MPU6050_ADDR);
  Wire.write(reg);
  Wire.write(value);
  return Wire.endTransmission() == 0;
}

bool imuReadRegs(uint8_t startReg, uint8_t* buf, uint8_t len) {
  Wire.beginTransmission(MPU6050_ADDR);
  Wire.write(startReg);
  if (Wire.endTransmission(false) != 0) {
    return false;
  }

  uint8_t read = Wire.requestFrom((int)MPU6050_ADDR, (int)len, (int)true);
  if (read != len) {
    return false;
  }

  for (uint8_t i = 0; i < len; i++) {
    buf[i] = Wire.read();
  }
  return true;
}

bool imuReadGyroZRaw(int16_t& gzRaw) {
  uint8_t data[2] = {0, 0};
  if (!imuReadRegs(0x47, data, 2)) {
    return false;
  }
  gzRaw = (int16_t)((data[0] << 8) | data[1]);
  return true;
}

bool imuCalibrateBias(uint16_t samples) {
  if (!imuOk || samples < 20) {
    return false;
  }

  float sum = 0.0f;
  float sumSq = 0.0f;
  uint16_t okCount = 0;
  for (uint16_t i = 0; i < samples; i++) {
    int16_t gzRaw = 0;
    if (imuReadGyroZRaw(gzRaw)) {
      float dps = ((float)gzRaw) / MPU6050_GYRO_Z_SCALE;
      sum += dps;
      sumSq += dps * dps;
      okCount++;
    }
    delay(2);
  }

  if (okCount < samples / 2) {
    imuCalValid = false;
    return false;
  }

  float mean = sum / (float)okCount;
  float variance = (sumSq / (float)okCount) - (mean * mean);
  imuCalStdDps = sqrtf(max(0.0f, variance));
  if (imuCalStdDps > MPU6050_CAL_MAX_STD_DPS) {
    imuCalValid = false;
    return false;
  }

  imuBiasDps = mean;
  imuGyroDps = 0.0f;
  imuGyroDpsFilt = 0.0f;
  imuCalValid = true;
  return true;
}

bool imuInit() {
  Wire.begin();
  delay(10);

  bool ok = true;
  ok &= imuWriteReg(0x6B, 0x00);  // Wake up MPU6050.
  ok &= imuWriteReg(0x1B, 0x08);  // Gyro FS_SEL=1 => +-500 dps.
  ok &= imuWriteReg(0x1A, 0x03);  // DLPF for less noise.
  delay(50);

  imuOk = ok;
  imuBiasDps = 0.0f;
  imuYawDeg = 0.0f;
  imuYawRawDeg = 0.0f;
  imuGyroDps = 0.0f;
  imuGyroDpsFilt = 0.0f;
  imuCalStdDps = 0.0f;
  imuCalValid = false;

  if (imuOk) {
    imuCalibrateBias(400);
  }
  return imuOk;
}

void imuUpdate(float dt) {
  if (!imuOk || dt <= 0.0001f) {
    imuGyroDps = 0.0f;
    imuGyroDpsFilt = 0.0f;
    return;
  }

  int16_t gzRaw = 0;
  if (!imuReadGyroZRaw(gzRaw)) {
    imuGyroDps = 0.0f;
    return;
  }

  imuGyroDps = ((float)gzRaw) / MPU6050_GYRO_Z_SCALE - imuBiasDps;
  imuGyroDpsFilt += MPU6050_GYRO_FILTER_ALPHA * (imuGyroDps - imuGyroDpsFilt);
  imuYawRawDeg = wrapAngleDeg(imuYawRawDeg + imuGyroDps * dt);
  imuYawDeg = wrapAngleDeg(imuYawDeg + imuGyroDpsFilt * dt);
}

void updateMecanumTargets() {
  float vx = constrain(commandForwardRpm, -RPM_TARGET_LIMIT, RPM_TARGET_LIMIT);
  float vy = constrain(commandStrafeRpm, -RPM_TARGET_LIMIT, RPM_TARGET_LIMIT) * (float)strafeSign;
  float omega = constrain(commandRotateRpm, -RPM_TARGET_LIMIT, RPM_TARGET_LIMIT) * (float)rotateSign;

  // Confirmed logical order [BR, FR, BL, FL].
  rawTargetRpm[0] = vx - vy + omega;
  rawTargetRpm[1] = vx + vy + omega;
  rawTargetRpm[2] = vx + vy - omega;
  rawTargetRpm[3] = vx - vy - omega;

  float maxAbsTarget = 0.0f;
  for (uint8_t i = 0; i < 4; i++) {
    maxAbsTarget = max(maxAbsTarget, fabsf(rawTargetRpm[i]));
  }

  targetScale = 1.0f;
  if (maxAbsTarget > RPM_TARGET_LIMIT && maxAbsTarget > 0.0001f) {
    targetScale = RPM_TARGET_LIMIT / maxAbsTarget;
  }

  for (uint8_t i = 0; i < 4; i++) {
    targetRpm[i] = constrain(rawTargetRpm[i] * targetScale, -RPM_TARGET_LIMIT, RPM_TARGET_LIMIT);
  }
}

float displayedOdomForwardCm() {
  return ((float)odomForwardSign) * odomForwardCm * odomForwardScale;
}

float displayedOdomStrafeCm() {
  return ((float)odomStrafeSign) * odomStrafeCm * odomStrafeScale;
}

float displayedOdomYawWheelCm() {
  return ((float)odomYawSign) * odomYawWheelCm;
}

float encoderYawDeg() {
  if (ENCODER_YAW_CM_PER_DEG <= 0.0001f) {
    return 0.0f;
  }
  return displayedOdomYawWheelCm() / ENCODER_YAW_CM_PER_DEG;
}

float displayedImuYawDeg() {
  return wrapAngleDeg(((float)odomYawSign) * imuYawDeg);
}

float displayedImuYawRawDeg() {
  return wrapAngleDeg(((float)odomYawSign) * imuYawRawDeg);
}

float displayedImuGyroDps() {
  return ((float)odomYawSign) * imuGyroDps;
}

float displayedImuGyroDpsFilt() {
  return ((float)odomYawSign) * imuGyroDpsFilt;
}

bool imuHeadingReady() {
  return imuOk && imuCalValid;
}

float displayedOdomYawDeg() {
  return imuHeadingReady() ? displayedImuYawDeg() : encoderYawDeg();
}
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
void loop() {
  vTaskDelay(pdMS_TO_TICKS(1000));
}

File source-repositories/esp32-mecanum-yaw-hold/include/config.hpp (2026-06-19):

#pragma once

#include <cstdint>

namespace app {

// -- Firmware mode --------------------------------------------------
constexpr const char* firmwareTransport() {
#if defined(APP_WIFI_DASHBOARD)
    return "wifi";
#else
    return "serial";
#endif
}

constexpr const char* firmwareSubsystem() {
#if defined(APP_WIFI_DASHBOARD) && defined(APP_STEPPER_BENCH)
    return "stepper_dashboard";
#elif defined(APP_WIFI_DASHBOARD) && defined(APP_JOYSTICK_DASHBOARD)
    return "base_joystick_dashboard";
#elif defined(APP_WIFI_DASHBOARD)
    return "base_dashboard";
#elif defined(APP_SERIAL_PID_BENCH)
    return "pid";
#elif defined(APP_SERIAL_STEPPER_BENCH)
    return "stepper";
#elif defined(APP_SERIAL_IMU_ENCODER_BENCH)
    return "imu_encoder";
#else
    return "unknown";
#endif
}

// -- Math constants -------------------------------------------------
constexpr float kPi = 3.14159265358979323846f;
constexpr float kGravityMps2 = 9.80665f;

// -- Serial ---------------------------------------------------------
constexpr uint32_t SERIAL_BAUD = 115200U;

// -- Wi-Fi sandbox console -----------------------------------------
constexpr const char* WIFI_AP_SSID = "AudixBench-ESP32";
constexpr const char* WIFI_AP_PASSWORD = "audixbench123";
constexpr uint8_t WIFI_AP_CHANNEL = 6U;
constexpr uint8_t WIFI_AP_MAX_CLIENTS = 4U;
constexpr uint16_t WIFI_HTTP_PORT = 80U;
constexpr uint16_t WIFI_WS_PORT = 81U;

// -- I2C / IMU ------------------------------------------------------
constexpr int IMU_SDA_PIN = 21;
constexpr int IMU_SCL_PIN = 22;
constexpr uint32_t I2C_FREQUENCY_HZ = 400000U;
constexpr uint8_t MPU6050_I2C_ADDRESS = 0x68U;
constexpr uint32_t IMU_GYRO_BIAS_SAMPLES = 500U;

// -- Limit switch ---------------------------------------------------
constexpr int LIMIT_SWITCH_PIN = 23;
constexpr bool LIMIT_SWITCH_ACTIVE_LOW = true;

// -- Stepper Wi-Fi bench -------------------------------------------
constexpr int STEPPER_STEP_PIN = 26;
constexpr int STEPPER_DIR_PIN = 25;
constexpr int STEPPER_ENABLE_PIN = 27;
constexpr bool STEPPER_ENABLE_ACTIVE_LOW = true;
constexpr bool STEPPER_UP_DIRECTION_HIGH = true;
constexpr int STEPPER_HOME_SWITCH_PIN = 4;
constexpr bool STEPPER_HOME_SWITCH_ACTIVE_LOW = true;
constexpr bool STEPPER_HOME_SWITCH_PULLUP = true;
constexpr float STEPPER_DEFAULT_RATE_HZ = 400.0f;
constexpr float STEPPER_DEFAULT_HOME_RATE_HZ = 250.0f;
constexpr float STEPPER_DEFAULT_HOME_TIMEOUT_SEC = 12.0f;
constexpr bool STEPPER_HOME_DIRECTION_UP = false;
constexpr bool STEPPER_AUTO_DISABLE_ON_IDLE = true;
constexpr uint32_t STEPPER_LOG_INTERVAL_MS = 1000U;
constexpr uint32_t STEPPER_PULSE_WIDTH_US = 12U;

// -- Encoder GPIO pins ----------------------------------------------
// Ordered: FL, FR, RL, RR
// Board labels from the current harness:
// FL=ENC2, FR=ENC3, RL/BL=ENC1, RR/BR=ENC4
constexpr int ENCODER_A_PINS[4] = {34, 33, 39, 25};
constexpr int ENCODER_B_PINS[4] = {35, 32, 36, 26};

// Encoder CPR (counts per revolution of motor output shaft), measured on the current hardware.
constexpr float ENCODER_COUNTS_PER_REV = 4346.8f;

inline float encoderCountToRad(int32_t counts) {
    return static_cast<float>(counts) * (2.0f * kPi / ENCODER_COUNTS_PER_REV);
}

inline float wrapAngleRad(float angle) {
    while (angle > kPi) {
        angle -= 2.0f * kPi;
    }
    while (angle < -kPi) {
        angle += 2.0f * kPi;
    }
    return angle;
}

// -- Motor driver GPIO pins ----------------------------------------
// Two-input H-bridge style, ordered: FL, FR, RL, RR.
// Board labels from the current harness:
// FL=MOTD, FR=MOTB, RL/BL=MOTC, RR/BR=MOTA
constexpr int MOTOR_IN1_PINS[4] = {17, 13, 4, 27};
constexpr int MOTOR_IN2_PINS[4] = {18, 19, 16, 14};
// +1 or -1 to flip physical wiring polarity per wheel
constexpr int MOTOR_POLARITY[4] = {1, -1, 1, -1};

// -- PWM ------------------------------------------------------------
constexpr uint32_t PWM_FREQUENCY = 2000U;
constexpr uint32_t PWM_RESOLUTION_BITS = 10U;
constexpr float PWM_MAX_F = 1023.0f;  // 2^10 - 1
constexpr float MOTOR_DEADBAND = 40.0f;  // counts below which motor stalls

// -- Mecanum kinematics ---------------------------------------------
constexpr float WHEEL_RADIUS_M = 0.0485f;
constexpr float WHEELBASE_HALF_M = 0.090f;  // half of 180 mm wheelbase
constexpr float TRACK_HALF_WIDTH_M = 0.147f;  // half of 294 mm track width

// -- PID gains ------------------------------------------------------
constexpr float PID_KP = 1.2f;
constexpr float PID_KI = 0.8f;
constexpr float PID_KD = 0.05f;
constexpr float PID_OUTPUT_MAX = 1.0f;
constexpr float PID_INTEGRAL_MAX = 50.0f;
constexpr float WHEEL_STOP_EPSILON_RAD_S = 0.05f;
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

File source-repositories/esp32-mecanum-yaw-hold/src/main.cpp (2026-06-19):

#include <Arduino.h>
#include <cstdint>

#include "bench_runtime.hpp"
#include "console_sink.hpp"
#include "config.hpp"
#include "encoder_isr.hpp"
#include "imu_driver.hpp"
#include "motor_driver.hpp"
#include "odometry.hpp"
#include "shared_state.hpp"
#include "stepper_bench.hpp"
#include "wifi_console.hpp"

namespace {

void printModeLine() {
    app::consolePrintf(
        "[mode] transport=%s subsystem=%s\n",
        app::firmwareTransport(),
        app::firmwareSubsystem());
}

void printBootHint() {
#if defined(APP_WIFI_DASHBOARD)
    app::consolePrintln("Wi-Fi dashboard mode active. Use the browser GUI for normal bench control.");
    app::consolePrintln("USB serial remains available for boot diagnostics only.");
#elif defined(APP_SERIAL_PID_BENCH)
    app::consolePrintln("Serial PID bench active. Type 'help' for PID/base commands.");
#elif defined(APP_SERIAL_STEPPER_BENCH)
    app::consolePrintln("Serial stepper bench active. Type 'help' for stepper, homing, and switch commands.");
#elif defined(APP_SERIAL_IMU_ENCODER_BENCH)
    app::consolePrintln("Serial IMU/encoder bench active. Type 'help' for feedback commands.");
#else
    app::consolePrintln("Unknown bench mode. Check PlatformIO environment flags.");
#endif
}

void printImuResult(bool imu_ready) {
#if defined(APP_BASE_BENCH) || defined(APP_IMU_ENCODER_BENCH)
    if (imu_ready) {
        app::consolePrintf(
            "IMU init OK: %s WHO_AM_I=0x%02X on I2C SDA=%d SCL=%d addr=0x%02X\n",
            app::imuDriver().detectedChipName(),
            app::imuDriver().detectedWhoAmI(),
            app::IMU_SDA_PIN,
            app::IMU_SCL_PIN,
            app::MPU6050_I2C_ADDRESS);
    } else {
        if (app::imuDriver().hasDetectedIdentity()) {
            app::consolePrintf(
                "IMU init FAILED: detected %s WHO_AM_I=0x%02X on I2C SDA=%d SCL=%d addr=0x%02X.\n",
                app::imuDriver().detectedChipName(),
                app::imuDriver().detectedWhoAmI(),
                app::IMU_SDA_PIN,
                app::IMU_SCL_PIN,
                app::MPU6050_I2C_ADDRESS);
        } else {
            app::consolePrintf(
                "IMU init FAILED: no WHO_AM_I response on I2C SDA=%d SCL=%d addr=0x%02X. Check power, wiring, and AD0/address.\n",
                app::IMU_SDA_PIN,
                app::IMU_SCL_PIN,
                app::MPU6050_I2C_ADDRESS);
        }
    }
#else
    (void)imu_ready;
#endif
}

}  // namespace

void setup() {
    Serial.begin(app::SERIAL_BAUD);
    const std::uint32_t serial_wait_start = millis();
    while (!Serial && (millis() - serial_wait_start) < 2000U) {
        delay(10);
    }

    app::initConsoleSink();
    app::initSharedState();
    app::initBenchRuntime();

#if defined(APP_BASE_BENCH) || defined(APP_IMU_ENCODER_BENCH)
    pinMode(app::LIMIT_SWITCH_PIN, app::LIMIT_SWITCH_ACTIVE_LOW ? INPUT_PULLUP : INPUT);
    app::initEncoders();
    app::resetEncoders();
    app::odometryTracker().reset();
    const bool imu_ready = app::imuDriver().begin();
#if defined(APP_BASE_BENCH)
    app::initMotorDriver();
#endif
#elif defined(APP_STEPPER_BENCH)
    app::initStepperBench();
    const bool imu_ready = false;
#else
    const bool imu_ready = false;
#endif

    app::consolePrintln();
    app::consolePrintln("Audix standalone ESP32 bench firmware ready.");
    printModeLine();
    printBootHint();
    printImuResult(imu_ready);
#if defined(APP_STEPPER_BENCH)
    app::consolePrintln("Stepper bench mode active. IMU, encoder, and base-motion hardware paths are intentionally skipped.");
#endif

#if defined(APP_WIFI_DASHBOARD)
    app::initWifiConsole();
#else
    app::consolePrintln("[wifi] disabled in this serial-only firmware environment.");
#endif

    xTaskCreatePinnedToCore(
        app::commandRxTask,
        "command_rx",
        app::COMMAND_TASK_STACK_BYTES,
        nullptr,
        app::COMMAND_TASK_PRIORITY,
        nullptr,
        0);

#if defined(APP_STEPPER_BENCH)
    xTaskCreatePinnedToCore(
        app::stepperBenchTask,
        "stepper_bench",
        app::STEPPER_TASK_STACK_BYTES,
        nullptr,
        app::STEPPER_TASK_PRIORITY,
        nullptr,
        1);
#elif defined(APP_BASE_BENCH)
    xTaskCreatePinnedToCore(
        app::motionControlTask,
        "motion_control",
        app::MOTION_TASK_STACK_BYTES,
        nullptr,
        app::MOTION_TASK_PRIORITY,
        nullptr,
        1);
#endif
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
